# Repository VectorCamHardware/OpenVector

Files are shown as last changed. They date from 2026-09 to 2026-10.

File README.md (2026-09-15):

# OpenVector

An open-source hardware and data repository for **VectorCam** — an AI-enabled mosquito-imaging tool built around a smartphone and a 3D-printed lens/light attachment. This repo holds everything a builder needs: the bill of materials, reference documents, and 3D-printable parts.

The full build guide — with an interactive parts list, cost calculator, and step-by-step instructions for Plan, Print, Assemble, Qualify, and Deploy — is here:

**[Build guide →](https://vectorcamhardware.github.io/OpenVector/)**

OpenVector is a community build guide. Visit [vectorcam.org](https://vectorcam.org) for more details.

## Repository structure
catalog/
catalog.csv Bill of materials — phones, hardware, filament, and lab equipment,
with sourcing links and cost. This is the source of truth for the
build guide's parts list; the guide re-syncs from this file.
docs/
tool-specifications.pdf
assembly-instructions.pdf
print-specifications.pdf
app-install.pdf
qualification-instructions.pdf
documentation-guidelines.pdf
stl/
3D-printable parts. See stl/README.md for the folder layout and naming convention.

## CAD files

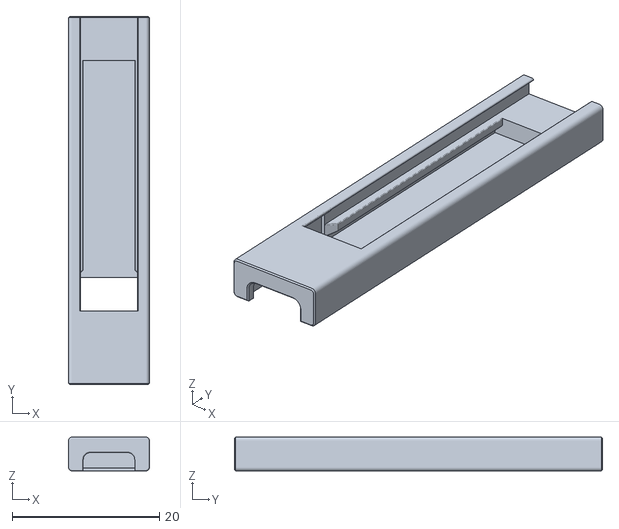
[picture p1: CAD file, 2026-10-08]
stl/MotorolaMotoGPlay/MotorolaMotoGPlay-LEDHolder.stl
11.0 x 50.0 x 4.60

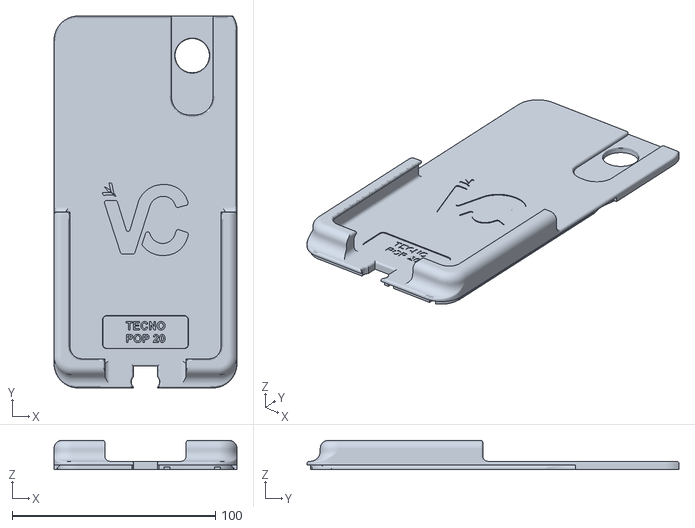
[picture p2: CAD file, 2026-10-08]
stl/TecnoPop20/TecnoPop20-Lid.stl
90.0 x 183.0 x 14.4

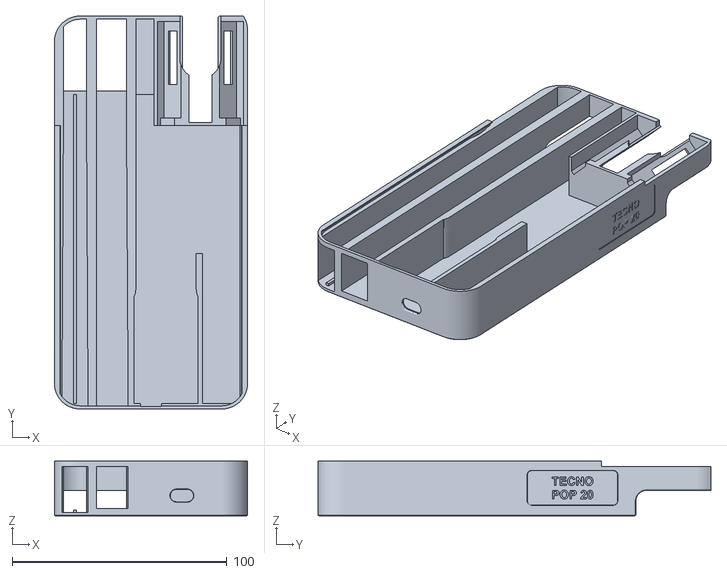
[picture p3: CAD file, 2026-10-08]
stl/TecnoPop20/TecnoPop20-Body.stl
90.0 x 183.0 x 25.4

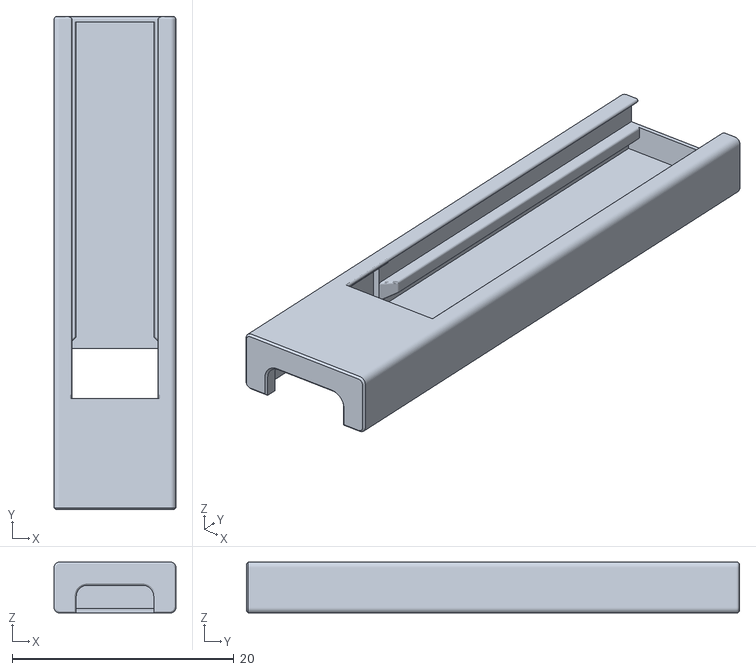
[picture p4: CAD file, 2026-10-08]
stl/TecnoPop20/TecnoPop20-LEDHolder.stl
11.0 x 44.5 x 4.60

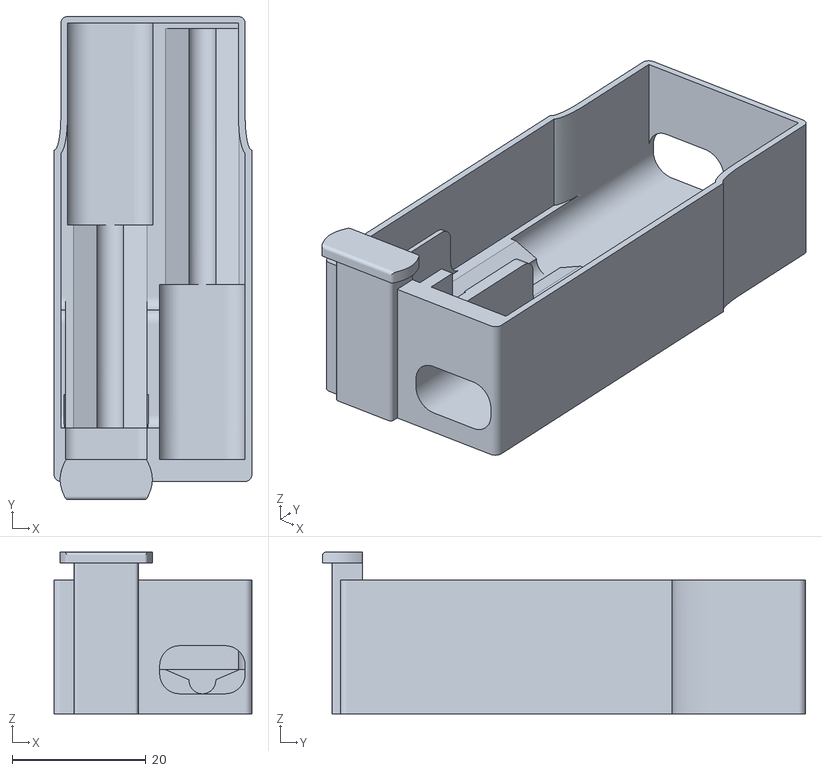
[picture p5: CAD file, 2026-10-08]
stl/TecnoPop20/TecnoPop20-CableManager.stl
29.6 x 72.3 x 24.2

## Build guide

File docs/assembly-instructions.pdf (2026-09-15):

## VectorCam Assembly Instructions

Document Details

Version 1.0

Last updated: 9/15/2026

Update Author: Thomas Huelskamp (thuelsk1@jhu.edu)

Author: Thomas Huelskamp (thuelsk1@jhu.edu)

Table of Contents

1.0 Printed Components
1.1 Component Checklist
1.2 VectorCam Body
1.3 VectorCam Lid
1.4 Body Insert
1.5 LED Frames
1.6 Mosquito Slides
1.7 Eppendorf Slide
2.0 Electronic and Optical Assembly 2.1 Component Checklist
2.2 Power Connector Assembly 2.3 Wire Preparation
2.4 LED Strip Wiring
2.5 LED Frame Assembly
2.6 Solderless Plug Wiring 2.7 Wiring Verification
2.8 Housing Assembly
3.0 Final Assembly and Verification 3.1 Lens Installation
3.2 Lid and Body Assembly
3.3 Final Verification

### 1.0 Printed Components

Tools required: needle-nose pliers, utility blade.

### 1.1 Component Checklist

Locate all 3D-printed components required for the assembly of one device:

- 1 VectorCam Body
- 1 VectorCam Lid
- 1 Body Insert
- 2 LED Frame
- 2 Mosquito Slide
- 1 Eppendorf Slide

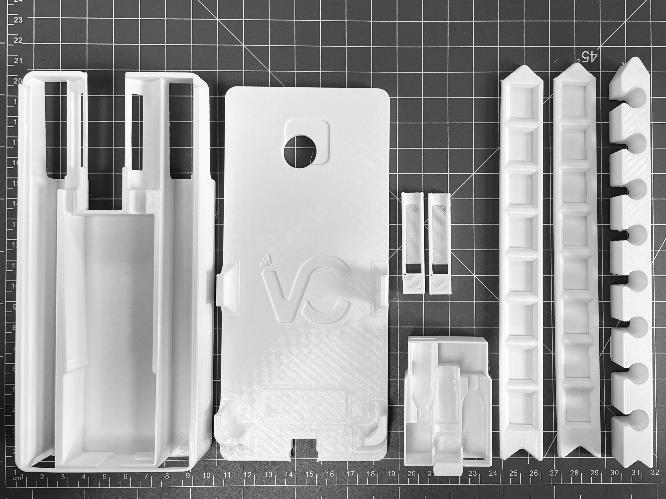
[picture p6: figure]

### 1.2 VectorCam Body

Remove any remaining support material and print overhangs in the following locations:

- bottom-side

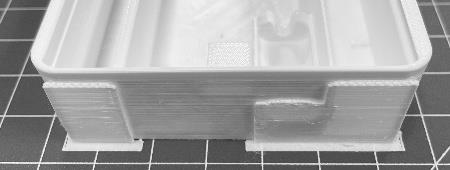
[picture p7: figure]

- USB-C window
- accessory windows

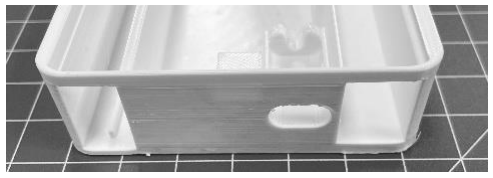
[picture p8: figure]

BAD — support material remaining | GOOD — no supports, clean edges

### 1.3 VectorCam Lid

Remove any remaining support material and print overhangs in the following locations:

- bottom-side
- side rails
- phone retainers
BAD — support material remaining | GOOD — no supports, clean edges

### 1.4 Body Insert

Remove any remaining support material and print overhangs in the following locations:

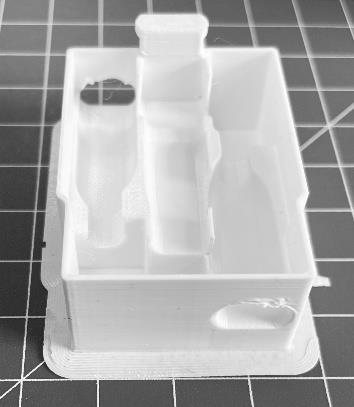
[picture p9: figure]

- USB-C windows
- base

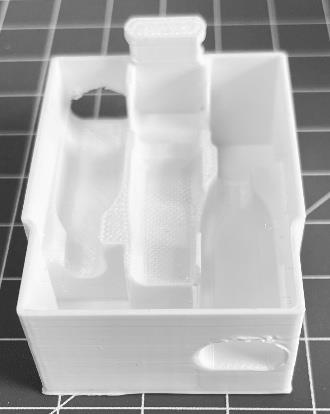
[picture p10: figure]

BAD — support material remaining | GOOD — no supports, clean edges

### 1.5 LED Frames

Remove any remaining support material and print overhangs in the following locations:

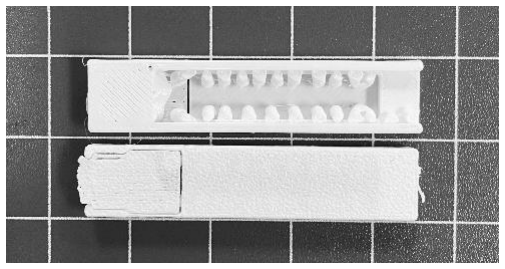
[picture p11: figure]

- bottom-side
- diffuser rails
BAD — support material remaining | GOOD — no supports, clean edges

### 1.6 Mosquito Slides

Remove any remaining support material and print overhangs in the following locations:

- edges
BAD — support material remaining | GOOD — no supports, clean edges

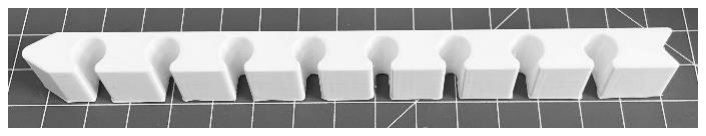
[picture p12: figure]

### 1.7 Eppendorf Slide

Remove any remaining support material and print overhangs in the following locations:

- edges
BAD — support material remaining | GOOD — no supports, clean edges

### 2.0 Electronic and Optical Assembly

Tools required: needle-nose pliers, wire strippers, small Phillips-head screwdriver, USB-C power source.

### 2.1 Component Checklist

Locate all electronic, optical, and 3D-printed components required for the assembly of one device:

- 1 USB-C adapter (180°)
- 1 USB-C splitter
- 1 USB-C solderless plug (5V)
- 2 red insulated wires (100mm)
- 2 green insulated wires (100mm)
- 2 solderless LED adapters
- 4 LED strips (2 nodes/strip)
- 4 diffusers (9mm x 35mm)
- 15x lens
- 1 set of 3D-printed device components
Electronic and optical components | 3D-printed device components

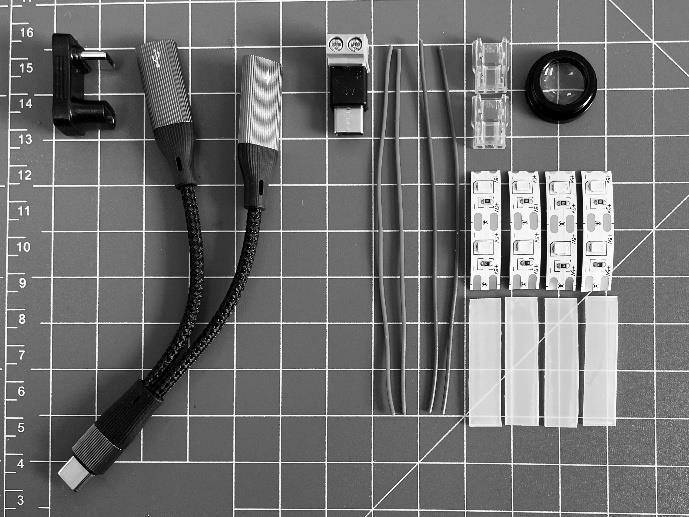
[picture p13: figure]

### 2.2 Power Connector Assembly

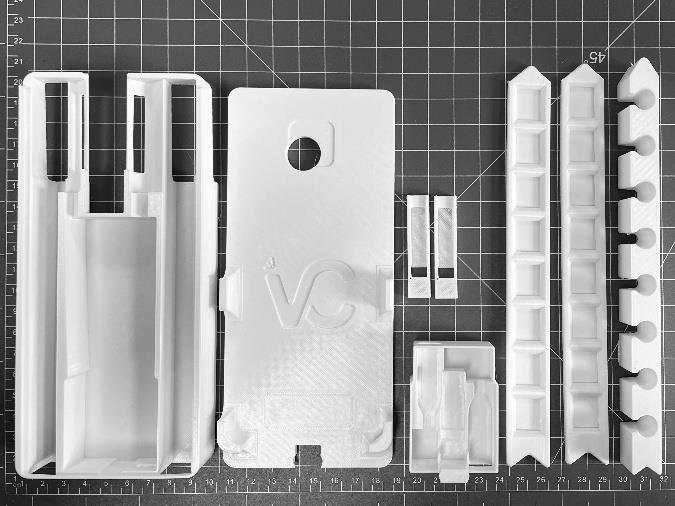
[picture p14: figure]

- Connect the female USB-C adapter to the male USB-C splitter, with the power input on the right and USB-C on the left.
- Insert the USB-C adapter and splitter assembly into the body insert, power input on the right and USB-C on the left.

- Insert the body insert into the VectorCam Body.
USB-C adapter connected to splitter | Adapter and splitter inserted into body insert

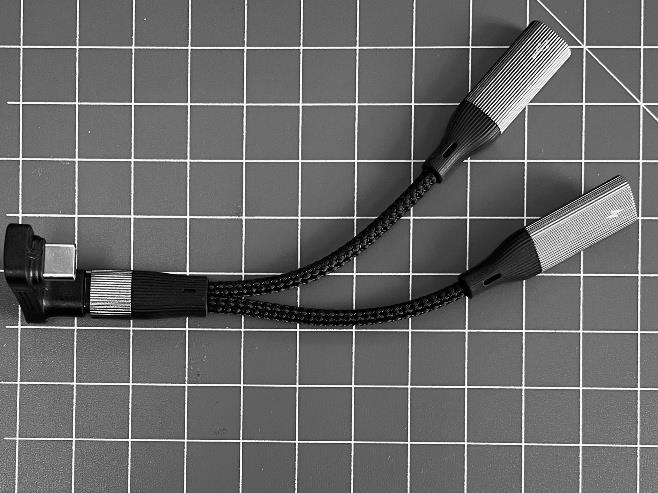
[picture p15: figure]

### 2.3 Wire Preparation

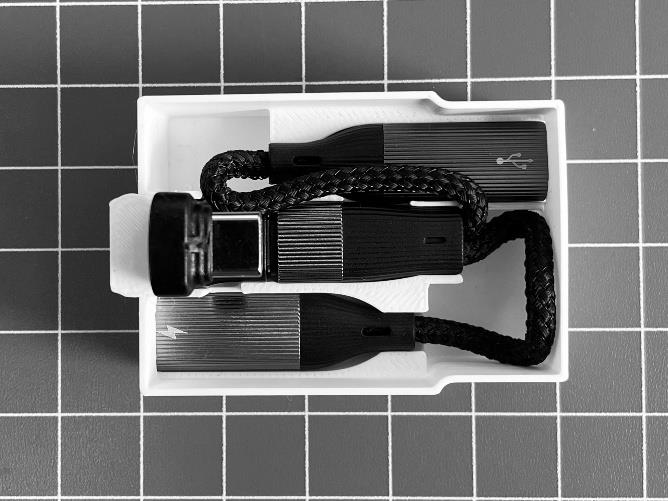
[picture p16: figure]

- Strip 5mm from both ends of each wire using wire strippers.
- Fold one end of each wire 180° using needle-nose pliers.

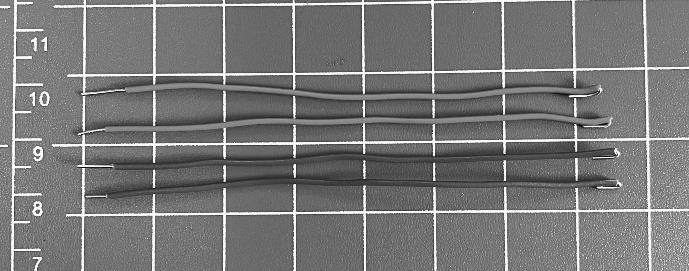
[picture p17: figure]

### 2.4 LED Strip Wiring

- Connect the wires to the lead end of the LED strip: red wire (+) and green wire (–) inside the LED adapter.
- Completely compress the LED adapter using needle-nose pliers.
- Repeat with the second LED strip, LED adapter, red wire, and green wire.
Wire connected at LED strip lead end | LED adapter compressed with pliers

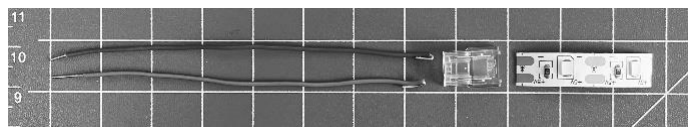
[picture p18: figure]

### 2.5 LED Frame Assembly

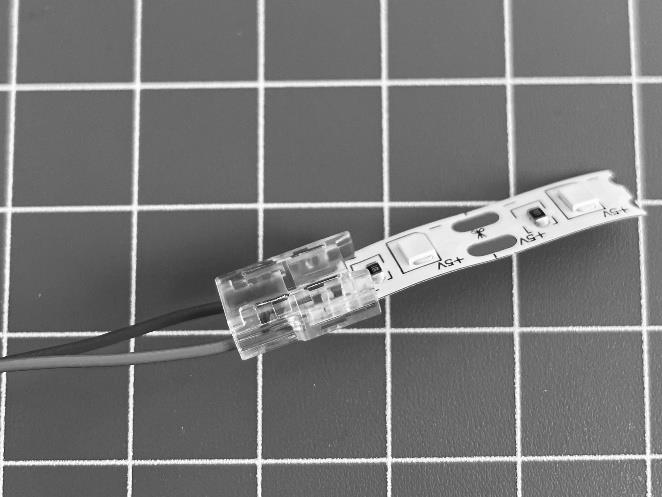
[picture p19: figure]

- Insert both LED strips into the LED frames and pinch the LED connector flush.
- Slide the diffusers into the LED frames.
- Verify that the diffusers are flush with the LED frames and do not fall short or extend too far.
- Verify that the diffusers are secure by holding the frame and shaking the wires.
LED strip installed in frame (1 of 2) | LED strip installed in frame (2 of 2)

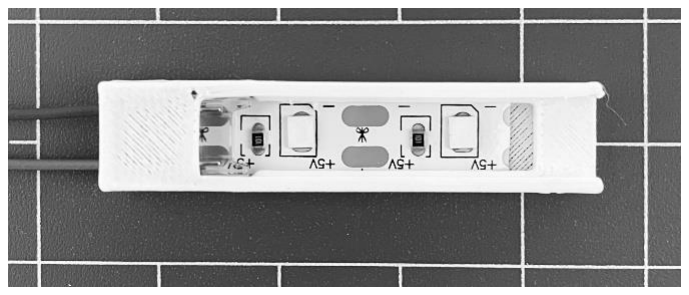
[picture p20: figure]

### 2.6 Solderless Plug Wiring

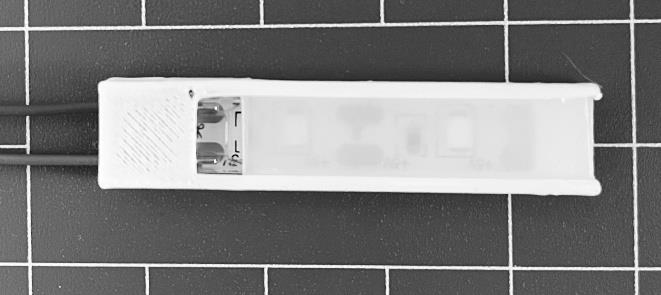
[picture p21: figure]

- Splice the red and green wires from each LED frame together using needle-nose pliers.
- Loosen both screws of the USB-C solderless plug.
- Fasten the spliced red (+) and green (–) wires in the USB-C solderless plug using the Phillips-head screwdriver.
Wires spliced together | Wires fastened in USB-C solderless plug

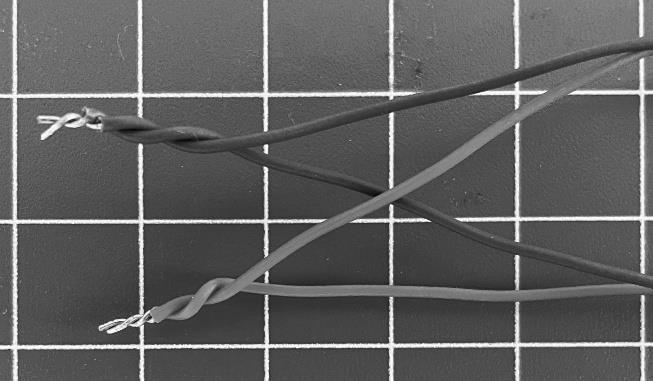
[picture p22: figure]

### 2.7 Wiring Verification

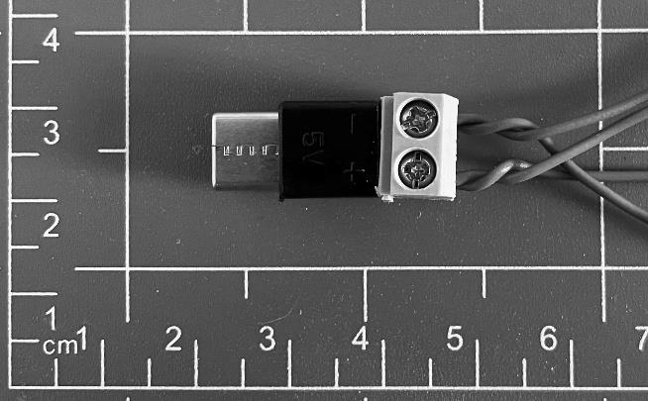
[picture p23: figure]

- Verify that the wires are securely attached to the LED strips by pulling on the connection.
- Verify that the wires are secure in the solderless plug by pulling on the connection.

### 2.8 Housing Assembly

- Insert the LED strips and frames into the VectorCam Body.
- Verify that the LED strips and frames are held in the VectorCam Body by tension.
- Connect the solderless plug to the body insert and USB-C assembly.

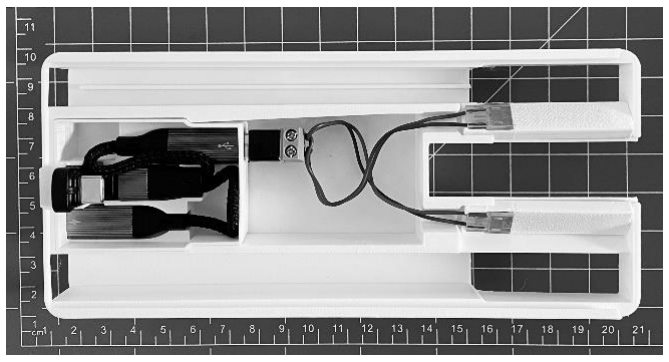
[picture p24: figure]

### 3.0 Final Assembly and Verification

### 3.1 Lens Installation

- Using a level surface, set the 15x lens into the VectorCam Lid.
- Verify that no visible gaps exist between the lid and the lens.
BAD — visible gap | GOOD — no gap

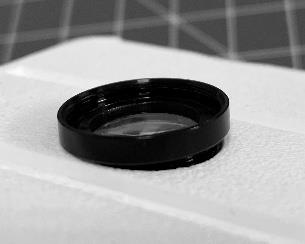
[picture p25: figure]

### 3.2 Lid and Body Assembly

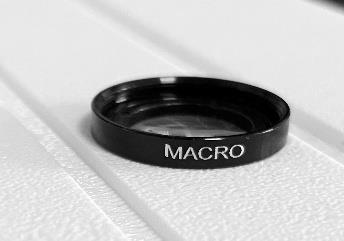
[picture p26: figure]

- Slide the assembled VectorCam Lid into the assembled VectorCam Body.
- Verify that the interface between the lid and body is flush.
- Verify that the lid, USB-C adapter, and body are flush.
GOOD — flush overview | GOOD — flush side edge | GOOD — flush USB-C corner

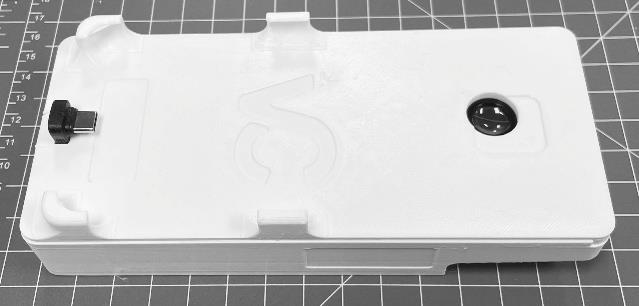
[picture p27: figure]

### 3.3 Final Verification

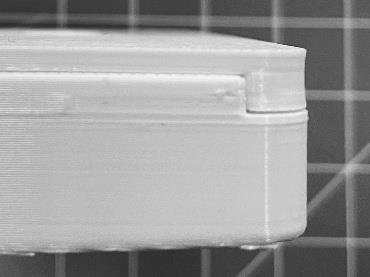
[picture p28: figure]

- Verify that all 4 LED nodes turn on when the complete device is connected to a USB-C power source.

GOOD — LED check

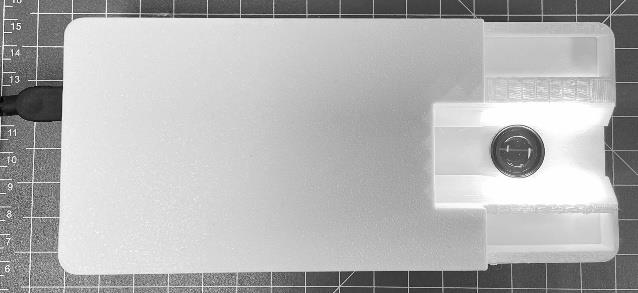
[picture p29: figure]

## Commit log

2026-09-21 Create Specimen ID Printer
2026-10-18 Rename Tray #2.stl to SpecimenTray2
2026-10-18 Sync STL list live from the repo; update snapshot to current stl/ files
    - Page reads stl/ from the GitHub API on load (falls back to the built-in snapshot)
    - Universal = files directly in stl/ or in stl/Universal/
    - Snapshot updated: SpecimenTray1/2, LEDHolder1/2 for Motorola and Tecno
    - Labels split trailing duplicate numbers (LED Holder 1, Specimen Tray 2)
2026-10-18 Add 'Download all as ZIP' to STL files
    Bundles the universal files plus the selected phone's files into one
    folder (VectorCam-STL-<Phone>/) inside a single zip. Files are fetched
    from the repo; JSZip 3.10.1 loads from cdnjs on first use.
    Claude-Session: https://claude.ai/code/session_013grTjXsWYUerwx7xWPAqrP
2026-10-19 Rename SpecimenTray2 (1).STL to SpecimenTray2.STL
2026-10-19 Rename TubeTray (2).STL to TubeTray.STL
